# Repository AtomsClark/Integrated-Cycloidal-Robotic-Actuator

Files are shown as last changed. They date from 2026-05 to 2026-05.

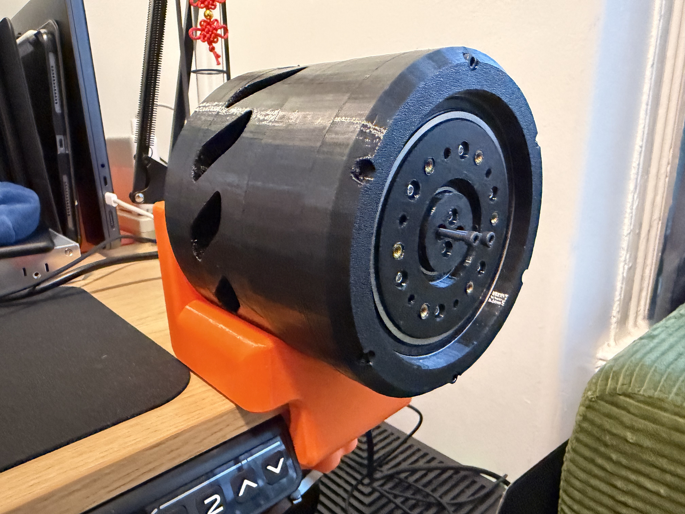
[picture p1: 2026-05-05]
media/photos/04-assembled-on-stand.jpg

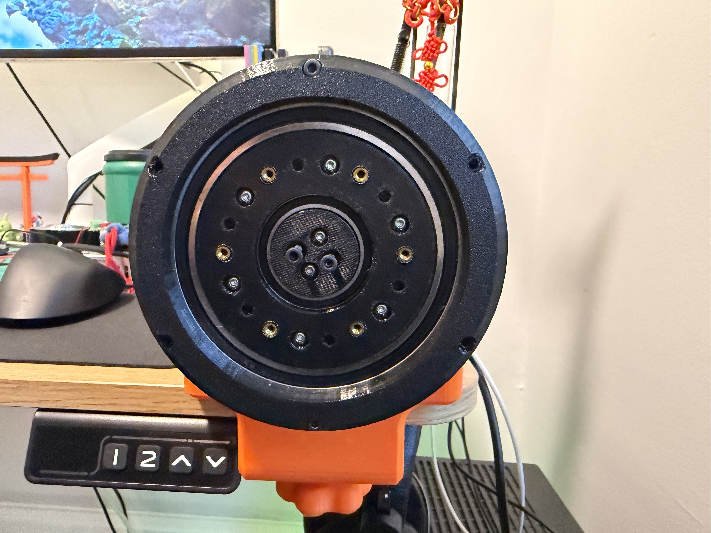
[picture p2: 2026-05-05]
media/photos/06-output-face.jpg

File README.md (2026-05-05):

# BLDC Integrated Cycloidal Actuator

A compact, high-torque robot joint actuator integrating an Eaglepower 8308 BLDC motor with a 3D-printed 19:1 cycloidal reduction. Designed and built January 2026 as a candidate joint for a humanoid robot.

A writeup of this project lives on my portfolio: <https://atomsclark.com/projects/cycloidal-actuator>. This repo holds the full source: CAD, photos, firmware artifacts, and tuning notes.

## Specs at a glance

| | |
|---|---|
| Reduction | 19:1 single-stage cycloidal |
| Cycloidal disc lobes | 19 (paired discs, 180° out of phase) |
| Ring-gear pins | 20, integrated to ring body |
| Output pins | 6 |
| Final torque | ~50 Nm |
| Efficiency | ~70% |
| Backlash | ~2° |
| Backdrivability | poor |
| Motor | Eaglepower 8308 BLDC |
| Controller | Flipsky ODESC V4.2 24V |
| Encoder | CUI Devices AMT103-V (incremental, 8192 CPR) |
| Mass | 3D-printed PETG / PLA on a Bambu P1P |
| Lubrication | white lithium grease |

## Repo layout

```
cad/
  v1.0/                  STLs + .3mf for the built version (Onshape source)
  archive/               Earlier iterations (V0, V0.1, V0.2) and disc source files
media/
  photos/                Real-world photos of parts and assembly
  cad-renders/           Onshape renders incl. cross-sections
firmware/
  FLIPSKY_ODESC_Programming.pages   Tuning notes from getting the controller running
  Flipsky_EDC_Default_Firmware.bin  Stock controller firmware (backup)
  ODriveFirmware_v3.6-24V_0.4.12.elf  ODrive 0.4.12 firmware that the ODESC matches
docs/
  CapstonePhase1_RobotRecordFlipper.key   Original concept slides
  MotorSizing.numbers                     Motor selection math
  CapstoneProject_BoM.numbers             Original BoM
```

## Bill of Materials

| Item | Qty | Cost |
|---|---:|---:|
| Eaglepower 8308 BLDC motor | 1 | $80 |
| Flipsky ODESC V4.2 24V FOC controller ([B0CB64MVHC](https://www.amazon.com/dp/B0CB64MVHC)) | 1 | $40 |
| CUI AMT103-V incremental encoder | 1 | $30 |
| 3×7×3 mm bearing — output pins ([B0DXZKVZMR](https://www.amazon.com/dp/B0DXZKVZMR)) | 12 | $15 |
| 6805-2RS bearing, 25×37×7 mm ([B082PYT33D](https://www.amazon.com/dp/B082PYT33D)) | 2 | $15 |
| 6806-2RS bearing, 30×42×7 mm ([B082PXK5K9](https://www.amazon.com/dp/B082PXK5K9)) | 2 | $15 |
| 6816-2RS bearing, 80×100×10 mm ([B07RQ4RXDR](https://www.amazon.com/dp/B07RQ4RXDR)) | 2 | $15 |
| M3 hardware + brass heat-set inserts | — | ~$25 |
| PETG + PLA filament | — | ~$15 |
| White lithium grease | — | ~$5 |
| **Total** | | **~$255** |

## Cycloidal Disc Geometry

Disc profiles started from STP files generated on [mevirtuoso.com/cycloidal-drive](https://mevirtuoso.com/cycloidal-drive/). I used 19 lobes on the disc paired with 20 ring-gear pins (N+1 convention) for the 19:1 reduction. Six output pins drive the common output disc.

## Print Settings

- Printer: Bambu P1P
- Materials: PETG (structural) and PLA (non-load-bearing parts)
- Heat-set inserts (M3 brass) for every fastener interface so the actuator can be reassembled without stripping plastic threads

## Controller Setup (Flipsky ODESC V4.2 → Eaglepower 8308)

The ODESC V4.2 advertises ODrive compatibility but ships with abandoned/forked firmware. Most of the integration time went into figuring out which `odrivetool` flags actually work against it and which gains keep the closed-loop transition from tripping a current-limit violation.

The full bench transcript (every command run, in order, including the iteration history) lives in [`firmware/odrivetool-session.md`](firmware/odrivetool-session.md). The minimal "what worked" sequence is below.

**Hardware**
- Flipsky ODESC V4.2 24V, ODrive-compatible firmware 0.4.12 (recovery image: `firmware/Flipsky_EDC_Default_Firmware.bin`; matching ODrive ELF: `firmware/ODriveFirmware_v3.6-24V_0.4.12.elf`)
- 12 V / 30 A bench PSU
- Eaglepower 8308 (90 Kv, 20 pole pairs)
- AMT103-V incremental encoder, 8192 CPR, index pulse used

**Power stage**
```python
odrv0.erase_configuration()
odrv0.config.brake_resistance        = 2
odrv0.config.dc_max_positive_current = 30
odrv0.config.dc_max_negative_current = -2.0
odrv0.config.max_regen_current       = 0
odrv0.save_configuration()
```

**Motor calibration**
```python
odrv0.axis0.motor.config.motor_type                   = MOTOR_TYPE_PMSM_CURRENT_CONTROL
odrv0.axis0.motor.config.pole_pairs                   = 20
odrv0.axis0.motor.config.torque_constant              = 8.27 / 90   # Kv = 90
odrv0.axis0.motor.config.resistance_calib_max_voltage = 5
odrv0.axis0.motor.config.calibration_current          = 2
odrv0.axis0.motor.config.current_lim                  = 22
odrv0.axis0.motor.config.requested_current_range      = 30

odrv0.axis0.requested_state = AXIS_STATE_MOTOR_CALIBRATION
odrv0.axis0.motor.config.pre_calibrated = True
odrv0.save_configuration()
```

**Encoder**
```python
odrv0.axis0.encoder.config.mode      = ENCODER_MODE_INCREMENTAL
odrv0.axis0.encoder.config.cpr       = 8192
odrv0.axis0.encoder.config.use_index = True
odrv0.axis0.requested_state = AXIS_STATE_FULL_CALIBRATION_SEQUENCE
odrv0.axis0.encoder.config.pre_calibrated = True
odrv0.save_configuration()
```

**Controller — final low-kick gains**
```python
odrv0.axis0.controller.config.control_mode = CONTROL_MODE_POSITION_CONTROL

# Walk pos/vel gains down from ODrive defaults to avoid the initial
# "kick" tripping current_lim_violation when entering closed loop at 12 V.
odrv0.axis0.controller.config.pos_gain            = 1.5
odrv0.axis0.controller.config.vel_gain            = 0.0001
odrv0.axis0.controller.config.vel_integrator_gain = 0.001

# 8192 counts/sec = 1 rev/sec — cap velocity to prevent overshoot at 12 V
odrv0.axis0.controller.config.vel_limit = 10000

# Wider current headroom so transients don't trip the violation
odrv0.axis0.motor.config.current_lim           = 20.0
odrv0.axis0.motor.config.current_lim_tolerance = 10.0

odrv0.axis0.config.startup_closed_loop_control = True
odrv0.save_configuration()
odrv0.reboot()
```

**Gotchas hit**
- ODrive's stock `pos_gain = 20` blew the current-limit violation as soon as `AXIS_STATE_CLOSED_LOOP_CONTROL` engaged — `pos_gain` had to come down to ~1.5 with `vel_gain = 0.0001` before the transient settled cleanly at 12 V.
- `current_lim_tolerance = 10.0` is generous, but anything tighter and the violation tripped on every encoder index search.
- Several newer ODrive config knobs silently no-op on the ODESC firmware — stick to the 0.4.12 surface area.

## Why this didn't ship in the humanoid

- **2° backlash** — printed cycloidal geometry has a hard floor on backlash without post-machining.
- **Poor backdrivability** — at 19:1 with printed friction surfaces, the joint can't be backdriven by hand, which kills compliant control schemes.
- **Cost per joint (~$255) and print time** — across all the DOFs I wanted, the BoM and assembly time put a full humanoid out of hobby budget.

So this build is now a self-contained study in BLDC + cycloidal joint design, and the humanoid moved to a different actuation strategy.

## License

Personal project — no license set. Ask before reusing.

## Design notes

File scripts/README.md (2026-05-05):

# Scripts

All scripts assume the [`odrive`](https://pypi.org/project/odrive/) Python package is installed and the ODESC V4.2 is reachable over USB.

```sh
pip install odrive
```

| Script | Purpose |
|---|---|
| `setup.py` | Apply the known-good config and run motor + encoder calibration. |
| `motion_tune.py` | Run a step sequence and drop into a REPL for live gain tweaking. |
| `characterize.py` | `--mode sweep` for no-load η / current draw across velocities; `--mode stall` for held-output torque tests against a known load. |
| `backlash.py` | Single-encoder backlash test — clamp the output, ramp current bidirectionally, infer slack from the engagement points where Iq spikes. |

## Recommended order

1. **Bench, unloaded** → `python setup.py`
2. **Bench, unloaded** → `python motion_tune.py` to walk gains up from defaults
3. **Bench, unloaded** → `python characterize.py --mode sweep` to log no-load efficiency curve
4. **Output clamped to lever arm** → `python characterize.py --mode stall --i-max 15` to measure transmission efficiency against a known mass × arm
5. **Output clamped solid** → `python backlash.py` (repeat at several output positions, average)

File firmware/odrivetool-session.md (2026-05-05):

# Flipsky ODESC V4.2 — `odrivetool` setup transcript

Verbatim transcription of the working notes from `FLIPSKY_ODESC_Programming.pages` (2026-02-24). Captures the iteration sequence used to get an Eaglepower 8308 turning under closed-loop position control on 12 V.

```
FLIPSKY ODESC V4.2 24V
FW 0.4.12
12V 30A PSU

odrivetool

odrv0.erase_configuration()

odrv0.config.brake_resistance = 2
odrv0.config.dc_max_positive_current = 30
odrv0.config.dc_max_negative_current = -2.0
odrv0.config.max_regen_current = 0
odrv0.save_configuration()

odrv0.axis0.motor.config.motor_type = MOTOR_TYPE_PMSM_CURRENT_CONTROL
odrv0.axis0.motor.config.pole_pairs = 20
odrv0.axis0.motor.config.torque_constant = 8.27/90
odrv0.axis0.motor.config.resistance_calib_max_voltage = 5
odrv0.axis0.motor.config.calibration_current = 2
odrv0.axis0.motor.config.current_lim = 22
odrv0.axis0.motor.config.requested_current_range = 30

odrv0.axis0.requested_state = AXIS_STATE_MOTOR_CALIBRATION
odrv0.axis0.motor
odrv0.axis0.motor.config.pre_calibrated = True
odrv0.axis0.encoder.config.calib_range = 0.1
odrv0.save_configuration()

odrv0.axis0.encoder.config.mode = ENCODER_MODE_INCREMENTAL
odrv0.axis0.controller.config.control_mode = CONTROL_MODE_POSITION_CONTROL
odrv0.axis0.encoder.config.cpr = 8192
odrv0.axis0.controller.config.pos_gain = 20
odrv0.axis0.controller.config.vel_gain = 0.02
odrv0.axis0.controller.config.vel_integrator_gain = 0.1
odrv0.axis0.controller.config.vel_limit = 100
odrv0.save_configuration()

odrv0.axis0.requested_state = AXIS_STATE_ENCODER_OFFSET_CALIBRATION
odrv0.axis0.encoder
odrv0.axis0.encoder.config.pre_calibrated = True
odrv0.axis0.requested_state = AXIS_STATE_CLOSED_LOOP_CONTROL
odrv0.axis0.config.startup_closed_loop_control = True
odrv0.save_configuration()
odrv0.reboot()

odrv0.axis0.encoder.config.use_index = True
odrv0.axis0.requested_state = AXIS_STATE_FULL_CALIBRATION_SEQUENCE
odrv0.axis0.motor.config.pre_calibrated = True
odrv0.axis0.encoder.config.pre_calibrated = True
odrv0.axis0.config.startup_closed_loop_control = True
odrv0.save_configuration()
odrv0.reboot()

odrv0.axis0.requested_state = AXIS_STATE_IDLE
odrv0.axis1.requested_state = AXIS_STATE_IDLE
odrv0.save_configuration()

odrv0.axis0.requested_state = AXIS_STATE_CLOSED_LOOP_CONTROL

odrv0.axis0.requested_state = AXIS_STATE_IDLE
odrv0.reboot()

odrv0.axis0.controller.config.vel_limit = 50000
odrv0.axis0.controller.config.vel_limit_tolerance = 2.0

odrv0.axis0.requested_state = AXIS_STATE_CLOSED_LOOP_CONTROL
odrv0.axis0.controller.pos_setpoint = 8192

odrv0.axis0.controller.config.control_mode = CONTROL_MODE_VELOCITY_CONTROL
odrv0.axis0.controller.config.vel_gain = 0.0001
odrv0.axis0.controller.config.vel_integrator_gain = 0.0001
odrv0.axis0.controller.config.pos_gain = 5
odrv0.axis0.controller.config.vel_ramp_rate = 2000
odrv0.axis0.controller.vel_ramp_enable = True
odrv0.axis0.motor.config.current_lim_tolerance = 5.0
odrv0.axis0.motor.config.current_control_bandwidth = 100
odrv0.save_configuration()

odrv0.axis0.encoder.shadow_count

# Set extremely low gains to prevent the initial "kick"
odrv0.axis0.controller.config.pos_gain = 1.5
odrv0.axis0.controller.config.vel_gain = 0.0001
odrv0.axis0.controller.config.vel_integrator_gain = 0.001

# Limit the speed so it doesn't overshoot at 12V
# 8192 counts/sec = 1 rotation per second
odrv0.axis0.controller.config.vel_limit = 10000

# Expand current headroom to avoid the violation trip
odrv0.axis0.motor.config.current_lim = 20.0
odrv0.axis0.motor.config.current_lim_tolerance = 10.0

odrv0.save_configuration()
odrv0.reboot()

odrv0.axis0.controller.pos_setpoint = 500
```

## Notes

- **Motor:** Eaglepower 8308, 90 Kv → `torque_constant = 8.27 / 90`, 20 pole pairs.
- **Encoder:** AMT103-V incremental, 8192 CPR, with index pulse used (`use_index = True`).
- **Calibration current:** 2 A, with `resistance_calib_max_voltage = 5 V`.
- **First-pass gains** that worked once but were too snappy: `pos_gain = 20`, `vel_gain = 0.02`, `vel_integrator_gain = 0.1`, `vel_limit = 100`.
- **Final low-kick gains** that survive the closed-loop transition at 12 V without tripping the `current_lim` violation: `pos_gain = 1.5`, `vel_gain = 0.0001`, `vel_integrator_gain = 0.001`, `vel_limit = 10000`, `current_lim = 20.0`, `current_lim_tolerance = 10.0`.
- **Velocity-mode tune:** `vel_gain = 0.0001`, `vel_integrator_gain = 0.0001`, `pos_gain = 5`, `vel_ramp_rate = 2000`, `vel_ramp_enable = True`, `current_control_bandwidth = 100`.
- **Test command:** `odrv0.axis0.controller.pos_setpoint = 500` (counts) for a small bench step once in `AXIS_STATE_CLOSED_LOOP_CONTROL`.

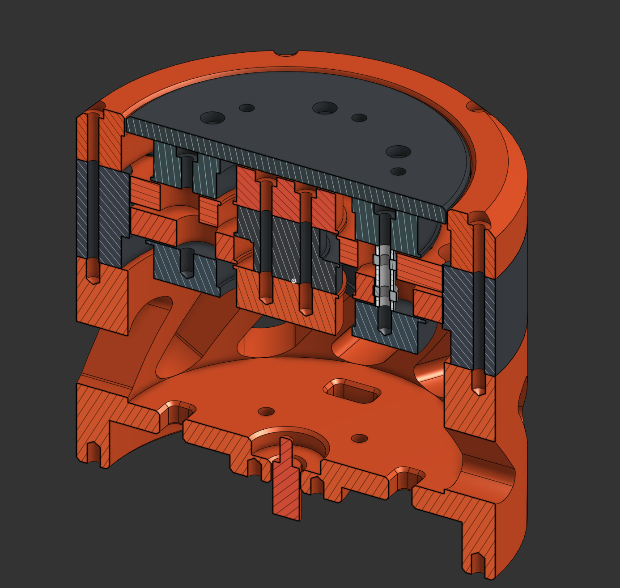
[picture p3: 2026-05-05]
media/cad-renders/cross-section-iso.png

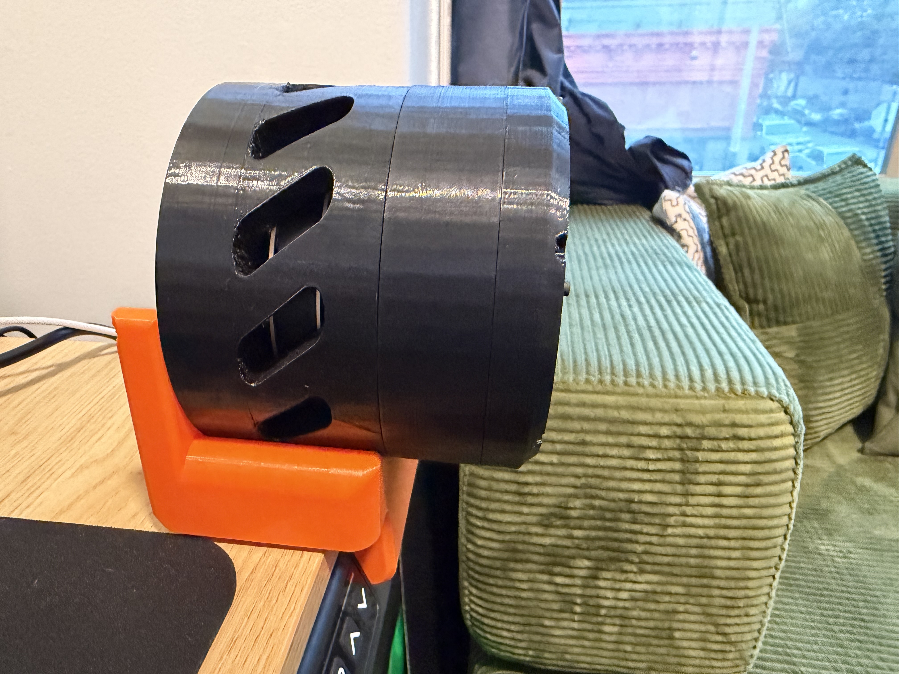
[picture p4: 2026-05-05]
media/photos/05-side-view.jpg

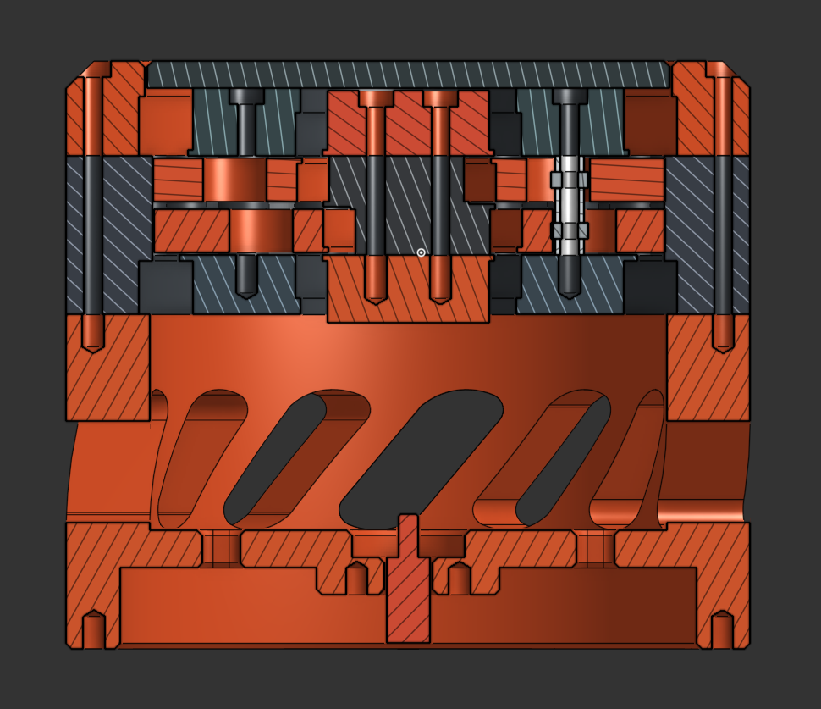
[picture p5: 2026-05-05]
media/cad-renders/cross-section-front.png

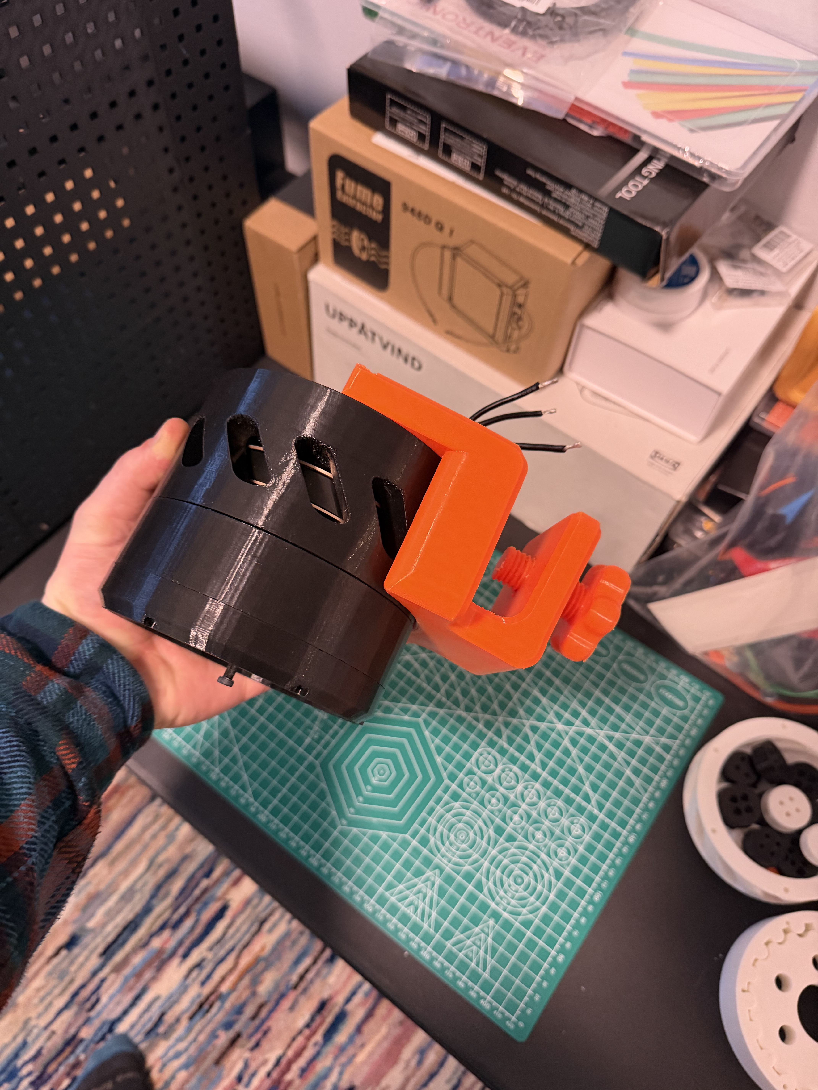
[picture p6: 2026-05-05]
media/photos/08-handheld-side.jpg

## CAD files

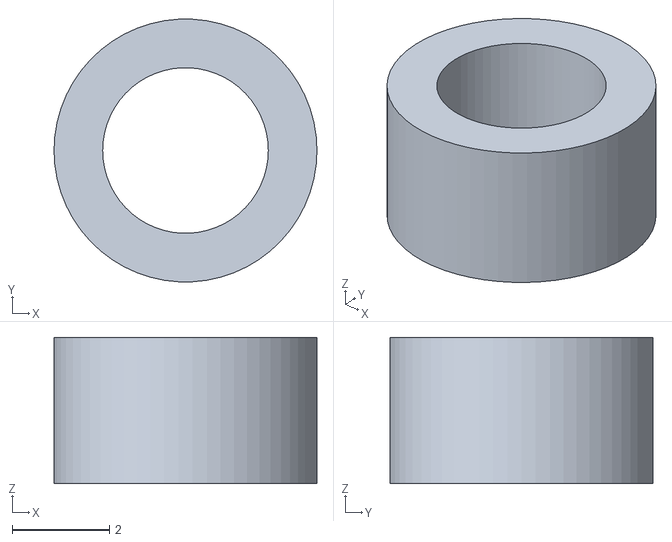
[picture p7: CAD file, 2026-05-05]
cad/v1.0/Part Studio 1 - Spacer_2.stl
5.40 x 5.39 x 3.00

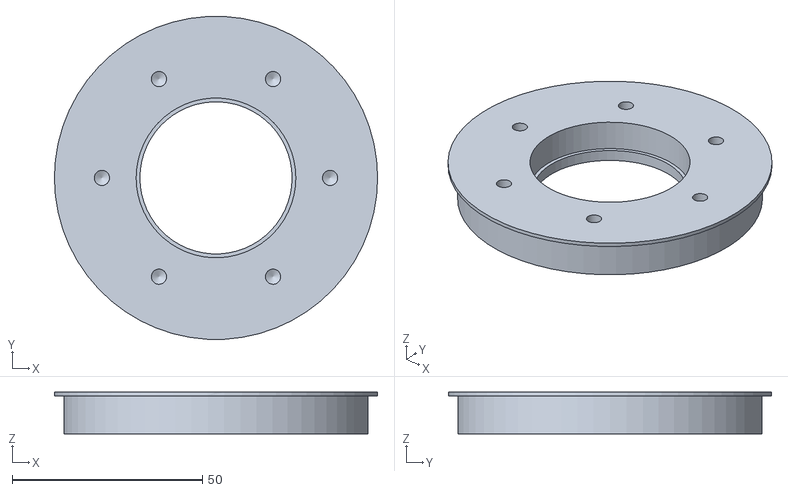
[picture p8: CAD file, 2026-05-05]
cad/v1.0/Part Studio 1 - OutputDisc_Bottom.stl
85.0 x 84.9 x 11.0

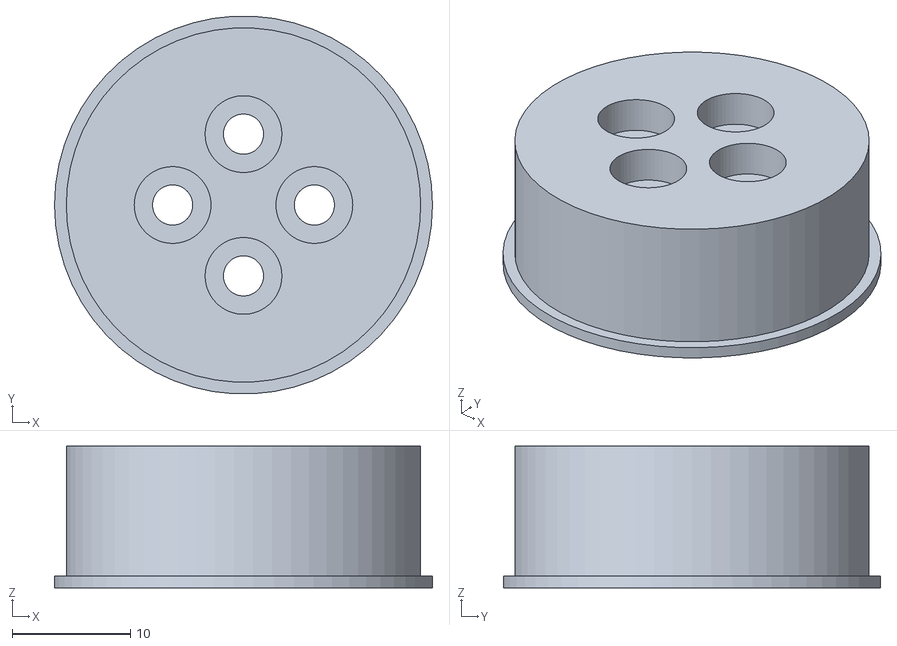
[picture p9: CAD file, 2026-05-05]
cad/v1.0/Part Studio 1 - Input_Shaft_Top.stl
32.0 x 32.0 x 12.0

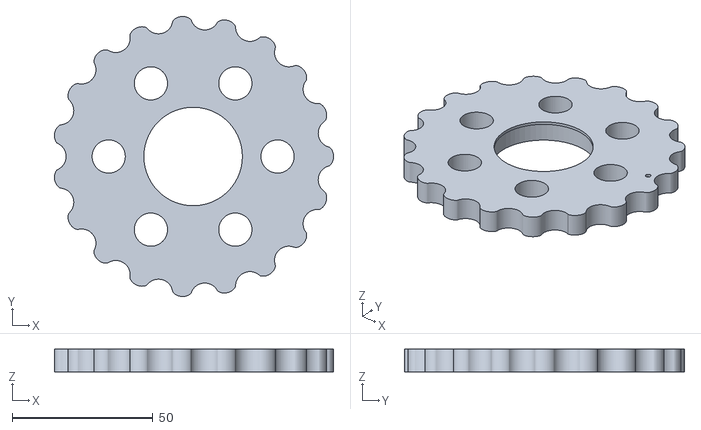
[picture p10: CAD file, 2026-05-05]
cad/v1.0/Part Studio 1 - CycloidalDisc_2.stl
99.2 x 99.5 x 8.00

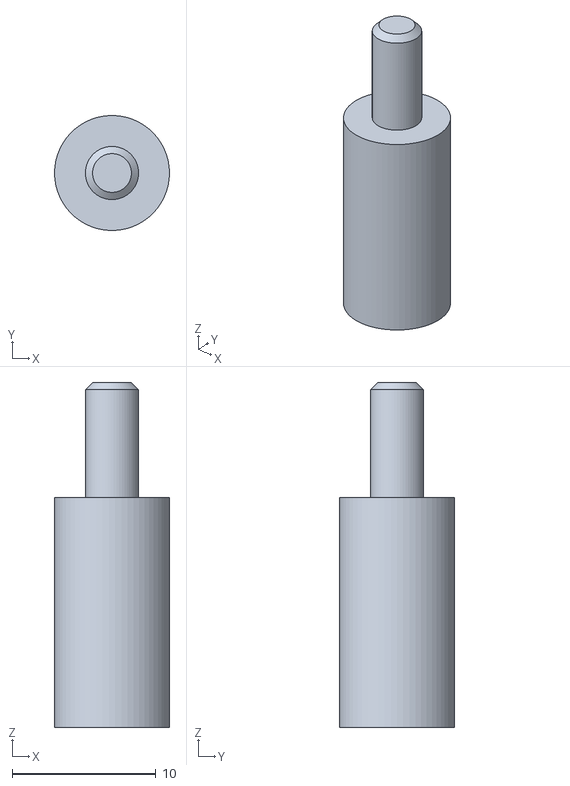
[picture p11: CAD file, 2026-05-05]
cad/v1.0/Part Studio 1 - Encoder_Shaft.stl
8.00 x 7.99 x 24.0

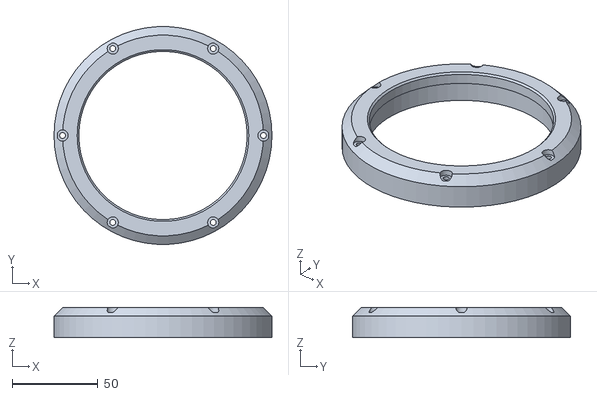
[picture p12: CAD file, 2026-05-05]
cad/v1.0/Part Studio 1 - End_RingGear.stl
127.0 x 126.8 x 17.5

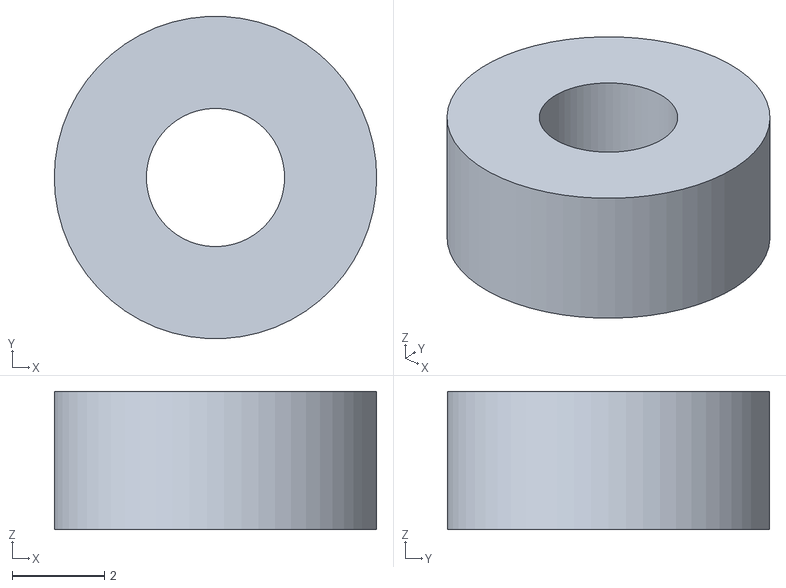
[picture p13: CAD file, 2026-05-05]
cad/v1.0/Part Studio 1 - Pin_Bearing_2.stl
7.00 x 6.99 x 3.00

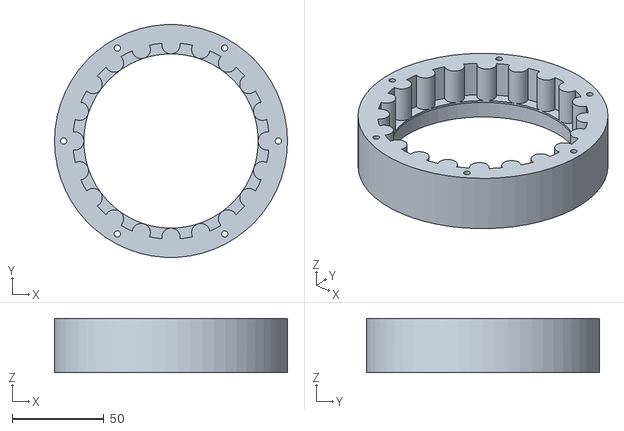
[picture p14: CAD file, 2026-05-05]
cad/v1.0/Part Studio 1 - RingGear.stl
127.0 x 126.8 x 29.5

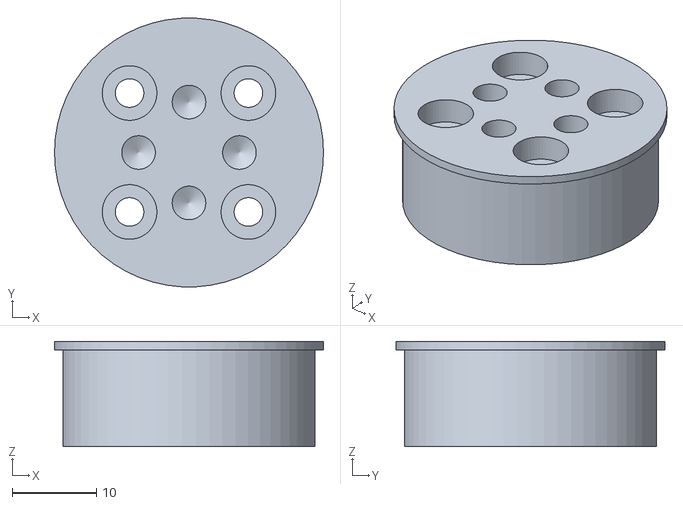
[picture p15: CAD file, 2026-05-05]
cad/v1.0/Part Studio 1 - Input_Shaft_Coupler.stl
32.0 x 32.0 x 12.5

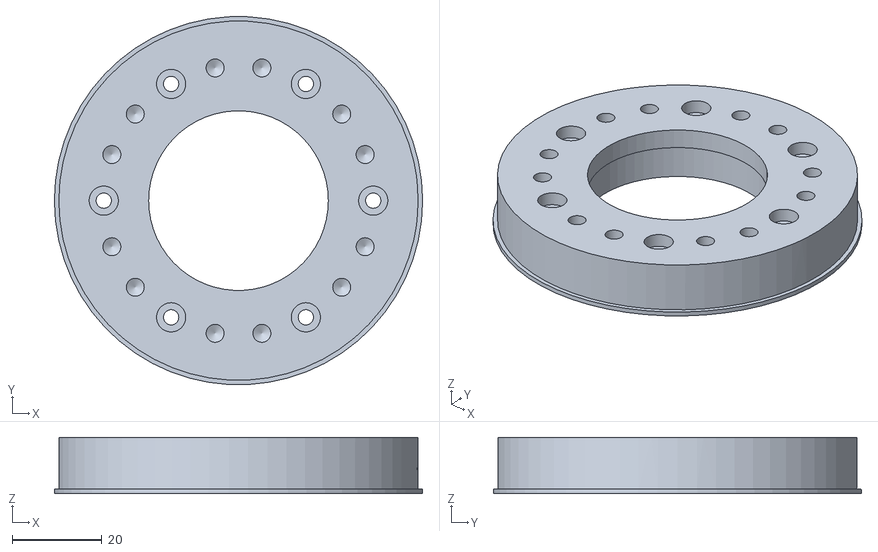
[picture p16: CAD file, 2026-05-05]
cad/v1.0/Part Studio 1 - OutputDisc_Top.stl
82.0 x 81.9 x 12.5

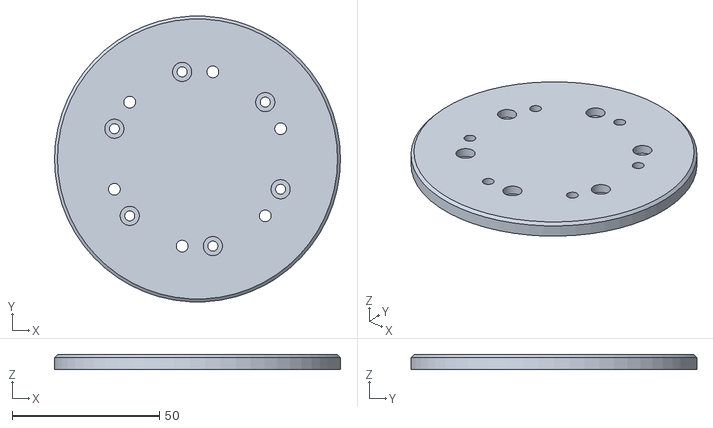
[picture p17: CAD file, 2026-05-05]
cad/v1.0/Part Studio 1 - Output_Shaft_Coupler.stl
97.0 x 96.9 x 5.00

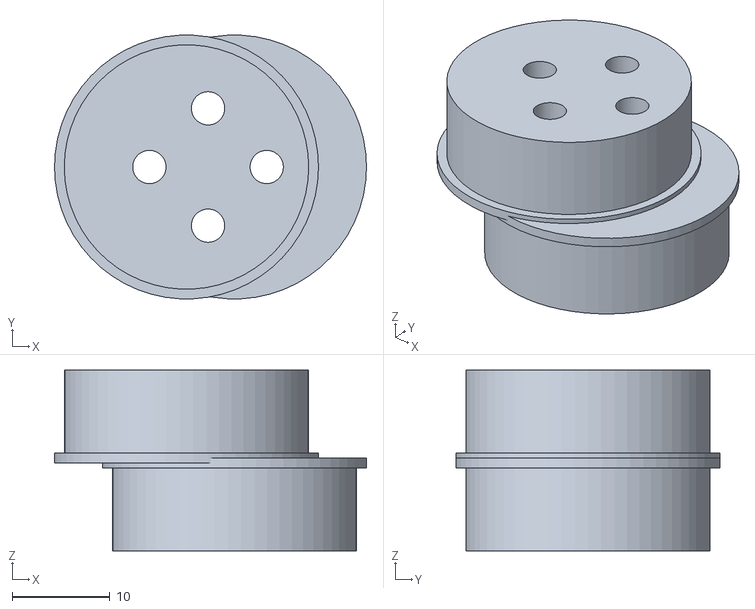
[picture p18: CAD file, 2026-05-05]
cad/v1.0/Part Studio 1 - Eccentric_Cam.stl
31.9 x 27.0 x 18.5

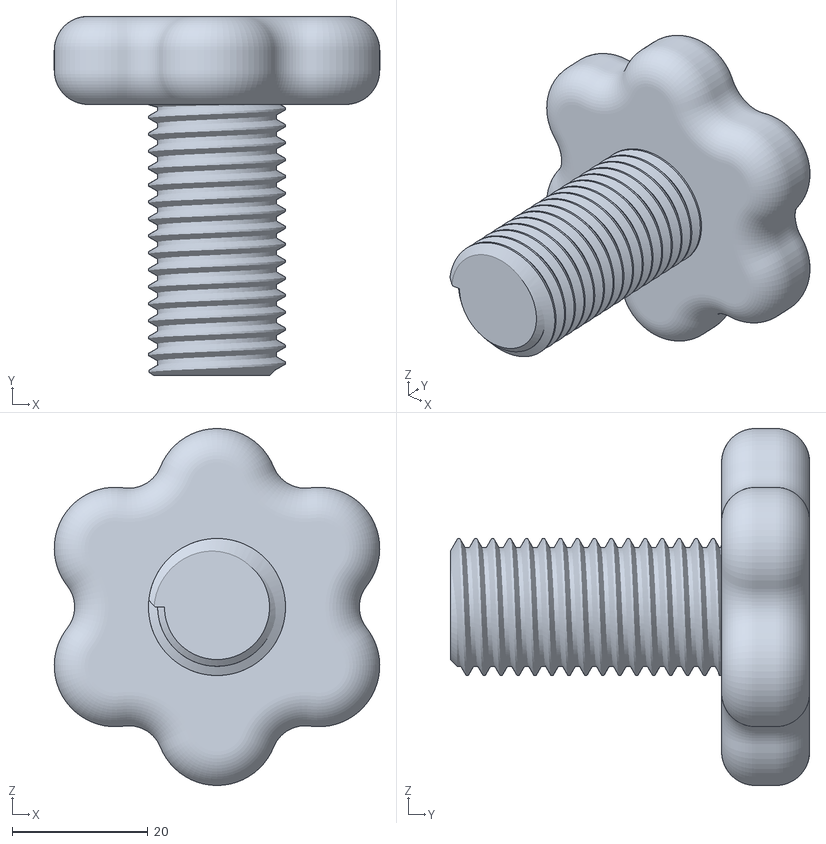
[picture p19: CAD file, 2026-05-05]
cad/v1.0/Part Studio 1 - Fixture_Knob.stl
48.0 x 53.0 x 52.6

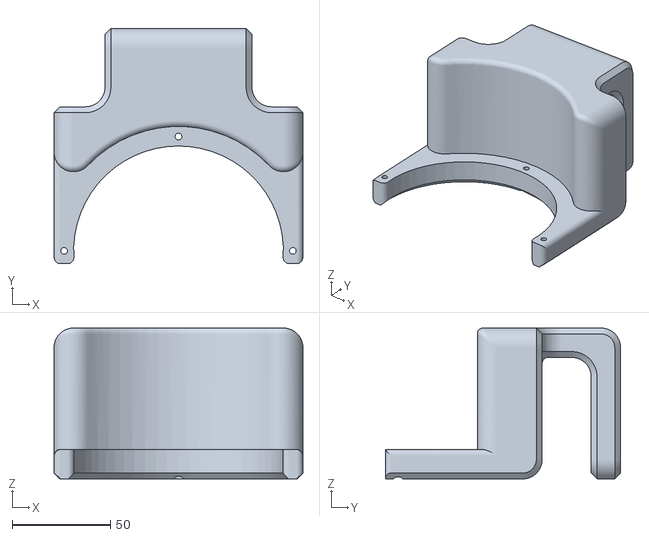
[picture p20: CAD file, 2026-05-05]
cad/v1.0/Part Studio 1 - Desk_Fixture.stl
127.0 x 120.0 x 77.0

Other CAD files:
cad/v1.0/Part Studio 1 - Spacer_1.stl
cad/v1.0/Part Studio 1 - Pin_Bearing_1.stl
cad/v1.0/Part Studio 1 - Spacer_3.stl
cad/v1.0/Cycloidal_Drive_V1.0.3mf
cad/archive/CycloidalDrive_V0.1/Part Studio 1 - CycloidalDisc_1.stl
cad/archive/CycloidalDrive_V0.1/Part Studio 1 - CycloidalDisc_2.stl
cad/archive/CycloidalDrive_V0.1/Part Studio 1 - End_RingGear.stl
cad/archive/CycloidalDrive_V0.1/Part Studio 1 - Input_Shaft_Coupler.stl
cad/archive/CycloidalDrive_V0.1/Part Studio 1 - Input_Shaft_Top.stl
cad/archive/CycloidalDrive_V0.1/Part Studio 1 - Motor_Housing.stl
cad/archive/CycloidalDrive_V0.1/Part Studio 1 - OutputDisc_Bottom.stl
cad/archive/CycloidalDrive_V0.1/Part Studio 1 - OutputDisc_Top.stl
cad/archive/CycloidalDrive_V0.1/Part Studio 1 - Output_Shaft_Coupler.stl
cad/archive/CycloidalDrive_V0.1/Part Studio 1 - Pin_Bearing_1.stl
cad/archive/CycloidalDrive_V0.1/Part Studio 1 - RingGear.stl
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

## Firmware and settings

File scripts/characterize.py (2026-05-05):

"""
Efficiency + torque-output characterization for the cycloidal actuator.

Two test modes; pick one with --mode.

--mode sweep
    No-load velocity sweep at fixed current cap. Logs:
        commanded vel, measured vel, Vbus, Iq, Ibus
    For each setpoint, computes
        electrical_in   = Vbus * Ibus
        mechanical_out_input_side = (Iq * Kt) * (vel * 2*pi)        [N·m·rad/s = W]
        mechanical_out_output_side = mechanical_out_input_side / GEAR_RATIO
                                     (assumes lossless reduction — i.e., this is
                                      the *upper bound* on output power)
    Useful for measuring electrical efficiency and idling losses, and for
    finding the velocity above which iron/friction losses dominate.

--mode stall
    Held-output torque test. CLAMP THE OUTPUT to a lever arm of known length L
    with a hanging mass m at the end. Setpoint ramps current from 0 to
    a configurable ceiling. Script logs Iq, Ibus, Vbus while you watch when
    the output starts to lift the mass. Pass the lift-off Iq with --kt to
    compute measured output torque vs theoretical (Iq * Kt * GEAR_RATIO),
    giving you a transmission efficiency number that doesn't assume a
    lossless reduction.

Both modes write a CSV next to this script.

Usage:
    python scripts/characterize.py --mode sweep
    python scripts/characterize.py --mode stall --i-max 15
"""

import argparse
import csv
import math
import time

import odrive
from odrive.enums import (
    AXIS_STATE_CLOSED_LOOP_CONTROL,
    AXIS_STATE_IDLE,
    CONTROL_MODE_POSITION_CONTROL,
    CONTROL_MODE_TORQUE_CONTROL,
    CONTROL_MODE_VELOCITY_CONTROL,
)

CPR = 8192
GEAR_RATIO = 19.0
KV = 90
KT = 8.27 / KV  # N·m / A


def connect():
    odrv = odrive.find_any()
    ax = odrv.axis0
    return odrv, ax


def sweep(odrv, ax, vels, dwell_s, out_path):
    ax.controller.config.control_mode = CONTROL_MODE_VELOCITY_CONTROL
    ax.controller.input_vel = 0
    ax.requested_state = AXIS_STATE_CLOSED_LOOP_CONTROL
    time.sleep(0.5)

    rows = []
    for v in vels:
        ax.controller.input_vel = v
        # let things settle
        time.sleep(dwell_s)
        # average over a window
        samples = []
        t_end = time.time() + 0.5
        while time.time() < t_end:
            samples.append({
                "t": time.time(),
                "vel_set": v,
                "vel": ax.encoder.vel_estimate,
                "Iq": ax.motor.current_control.Iq_measured,
                "Ibus": odrv.ibus,
                "Vbus": odrv.vbus_voltage,
            })
            time.sleep(0.005)

        avg = lambda k: sum(s[k] for s in samples) / len(samples)
        v_mean = avg("vel")          # counts/sec on input shaft
        Iq = avg("Iq")
        Ibus = avg("Ibus")
        Vbus = avg("Vbus")

        omega_in = (v_mean / CPR) * 2 * math.pi    # rad/s on input shaft
        omega_out = omega_in / GEAR_RATIO          # rad/s on output shaft
        tau_motor = Iq * KT                        # N·m on input shaft
        p_mech_in = abs(tau_motor * omega_in)
        p_mech_out_max = p_mech_in                  # upper bound (lossless gearbox)
        p_elec = abs(Vbus * Ibus)
        eta_elec = (p_mech_in / p_elec) if p_elec > 1e-3 else 0.0

        rows.append({
            "vel_set_cps": v,
            "vel_meas_cps": v_mean,
            "omega_in_rad_s": omega_in,
            "omega_out_rad_s": omega_out,
            "Iq_A": Iq,
            "Ibus_A": Ibus,
            "Vbus_V": Vbus,
            "tau_motor_Nm": tau_motor,
            "p_elec_W": p_elec,
            "p_mech_W": p_mech_in,
            "eta_electrical": eta_elec,
        })
        print(f"  v={v:>6.0f}  Iq={Iq:+.2f}A  Ibus={Ibus:+.2f}A  "
              f"P_in={p_elec:5.1f}W  P_mech={p_mech_in:5.1f}W  "
              f"η_elec={eta_elec*100:4.1f}%")

    ax.controller.input_vel = 0
    ax.requested_state = AXIS_STATE_IDLE

    with open(out_path, "w", newline="") as f:
        w = csv.DictWriter(f, fieldnames=list(rows[0].keys()))
        w.writeheader()
        w.writerows(rows)
    print(f"\nSweep log: {out_path}")


def stall(odrv, ax, i_max, ramp_s, out_path):
    """
    Output must be clamped to a lever arm with a known load.
    The script ramps torque setpoint from 0 to KT*i_max.
    Operator records the Iq at which the load lifts off.
    """
    ax.controller.config.control_mode = CONTROL_MODE_TORQUE_CONTROL
    ax.controller.input_torque = 0
    ax.requested_state = AXIS_STATE_CLOSED_LOOP_CONTROL
    time.sleep(0.5)

    print("Stall test starting in 3 s — ensure output is clamped to lever arm.")
    time.sleep(3)

    rows = []
    n = max(1, int(ramp_s / 0.05))
    for i in range(n + 1):
        frac = i / n
        target_torque_motor = frac * (i_max * KT)
        ax.controller.input_torque = target_torque_motor
        time.sleep(0.05)
        rows.append({
            "t": time.time(),
            "torque_set_motor_Nm": target_torque_motor,
            "Iq_A": ax.motor.current_control.Iq_measured,
            "Ibus_A": odrv.ibus,
            "Vbus_V": odrv.vbus_voltage,
            "shadow": ax.encoder.shadow_count,
            "vel": ax.encoder.vel_estimate,
        })
        print(f"  τ_set={target_torque_motor:.3f} Nm motor "
              f"({target_torque_motor*GEAR_RATIO:.2f} Nm out, lossless)  "
              f"Iq={rows[-1]['Iq_A']:+.2f}A  vel={rows[-1]['vel']:+.0f}cps")

    ax.controller.input_torque = 0
    ax.requested_state = AXIS_STATE_IDLE

    with open(out_path, "w", newline="") as f:
        w = csv.DictWriter(f, fieldnames=list(rows[0].keys()))
        w.writeheader()
        w.writerows(rows)
    print(f"\nStall log: {out_path}")
    print("Lift-off torque (output) = Iq_at_liftoff * Kt * GEAR_RATIO * η_mech.")
    print("Compare to m * g * L (mass * gravity * lever-arm length) for η_mech.")


def main():
    p = argparse.ArgumentParser()
    p.add_argument("--mode", choices=("sweep", "stall"), required=True)
    p.add_argument("--i-max", type=float, default=15.0,
                   help="stall: max motor current (A) at end of ramp")
    p.add_argument("--ramp-s", type=float, default=10.0,
                   help="stall: ramp duration (s)")
    p.add_argument("--vmin", type=float, default=2000)
    p.add_argument("--vmax", type=float, default=30000)
    p.add_argument("--vsteps", type=int, default=8)
    p.add_argument("--dwell", type=float, default=1.0,
                   help="sweep: settle time per setpoint (s)")
    args = p.parse_args()

    odrv, ax = connect()
    try:
        if args.mode == "sweep":
            step = (args.vmax - args.vmin) / max(1, args.vsteps - 1)
            vels = [args.vmin + step * i for i in range(args.vsteps)]
            vels = [+v for v in vels] + [-v for v in vels]
            sweep(odrv, ax, vels, args.dwell, "sweep_log.csv")
        else:
            stall(odrv, ax, args.i_max, args.ramp_s, "stall_log.csv")
    finally:
        ax.requested_state = AXIS_STATE_IDLE


if __name__ == "__main__":
    main()

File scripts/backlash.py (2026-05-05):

"""
Single-encoder backlash test for the cycloidal actuator.

Idea
----
With only an input-side encoder you can't directly measure output position,
but you *can* measure the moment the gearbox starts loading the motor.
Inside the backlash zone, the input shaft turns freely (current ≈ 0).
The instant the lobes engage, current spikes.

So: rigidly clamp the output, command a slow position ramp on the input,
log Iq vs shadow_count, and look for the steep rise. Reverse direction and
do it again. The angular distance between the two engagement points,
divided by the gear ratio, is the output-referred backlash.

Procedure
---------
1. Clamp the output disc to the desk fixture so it cannot rotate.
2. Run this script. It will:
     a. Drive +0.5 motor revs at low gain to find the +engagement point
        (Iq crosses --i-thresh).
     b. Reverse and drive -1.0 motor revs to find the -engagement point.
     c. Compute Δshadow between engagement points → input-shaft slack.
     d. Output backlash (deg) = (Δshadow / CPR) * 360 / GEAR_RATIO.
3. Repeat at multiple output positions (re-clamp, re-run). Backlash
   typically varies a bit around the rotation because of disc geometry
   tolerances; report mean ± range.

Tips
----
- Run on a stiff bench; any compliance in the clamp shows up as backlash.
- Use a small --i-thresh (e.g. 0.5 A) for sensitivity, but high enough to
  reject Iq noise.
- This measures total system slack: ring-pin clearance + disc-bore
  clearance + output-pin slop + any flex in the printed parts. That's
  fine — it's also what a downstream controller experiences.

Usage:
    python scripts/backlash.py --i-thresh 0.5 --speed 5000
"""

import argparse
import csv
import math
import time

import odrive
from odrive.enums import (
    AXIS_STATE_CLOSED_LOOP_CONTROL,
    AXIS_STATE_IDLE,
    CONTROL_MODE_VELOCITY_CONTROL,
)

CPR = 8192
GEAR_RATIO = 19.0


def connect():
    odrv = odrive.find_any()
    ax = odrv.axis0
    ax.controller.config.control_mode = CONTROL_MODE_VELOCITY_CONTROL
    ax.controller.input_vel = 0
    ax.requested_state = AXIS_STATE_CLOSED_LOOP_CONTROL
    time.sleep(0.3)
    return odrv, ax


def find_engagement(ax, direction, speed, i_thresh, max_revs, log):
    """
    Drive at constant velocity until |Iq| crosses i_thresh.
    Returns the shadow_count at the moment of engagement, or None if
    we ran the full max_revs without seeing engagement.
    """
    start = ax.encoder.shadow_count
    limit = start + direction * int(max_revs * CPR)

    ax.controller.input_vel = direction * speed
    engagement = None
    while True:
        s = ax.encoder.shadow_count
        iq = ax.motor.current_control.Iq_measured
        log.append({
            "t": time.time(),
            "shadow": s,
            "Iq": iq,
            "vel_set": direction * speed,
        })
        if abs(iq) > i_thresh:
            engagement = s
            break
        if (direction > 0 and s >= limit) or (direction < 0 and s <= limit):
            break
        time.sleep(0.002)

    ax.controller.input_vel = 0
    time.sleep(0.2)
    return engagement


def main():
    p = argparse.ArgumentParser()
    p.add_argument("--i-thresh", type=float, default=0.5,
                   help="Iq (A) threshold that marks engagement")
    p.add_argument("--speed", type=float, default=5000,
                   help="counts/sec while searching")
    p.add_argument("--max-revs", type=float, default=0.5,
                   help="abort search after this many motor revs in one direction")
    args = p.parse_args()

    odrv, ax = connect()
    log = []
    try:
        print(f"Searching for + engagement at vel={args.speed} cps "
              f"(threshold {args.i_thresh} A)...")
        s_plus = find_engagement(ax, +1, args.speed, args.i_thresh,
                                 args.max_revs, log)
        if s_plus is None:
            raise RuntimeError("no + engagement found — output not clamped?")
        print(f"  + engagement at shadow={s_plus}")

        print("Reversing to find - engagement...")
        s_minus = find_engagement(ax, -1, args.speed, args.i_thresh,
                                  args.max_revs * 2, log)
        if s_minus is None:
            raise RuntimeError("no - engagement found")
        print(f"  - engagement at shadow={s_minus}")

        delta_counts = abs(s_plus - s_minus)
        input_deg = (delta_counts / CPR) * 360.0
        output_deg = input_deg / GEAR_RATIO
        print(f"\nInput-shaft slack:  {delta_counts} counts ({input_deg:.2f}°)")
        print(f"Output backlash:    {output_deg:.3f}°"
              f"  (over {GEAR_RATIO}:1 reduction)")
    finally:
        ax.requested_state = AXIS_STATE_IDLE
        with open("backlash_log.csv", "w", newline="") as f:
            w = csv.DictWriter(f, fieldnames=list(log[0].keys()))
            w.writeheader()
            w.writerows(log)
        print("Trace: backlash_log.csv")


if __name__ == "__main__":
    main()

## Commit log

2026-05-05 Initial commit: V1.0 CAD, photos, firmware notes, docs
    [Cycloidal_Drive_V1.0.3mf, Disc-D100-E2_300-Dp7-N20-Phase1-Disc1.dxf, Disc-D100-E2_300-Dp7-N20-Phase2-Disc1.dxf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]
2026-05-05 firmware: fill in real odrivetool values + verbatim transcript
2026-05-05 scripts: setup, motion+tuning, characterization, backlash test
    [backlash.py, characterize.py, motion_tune.py]
